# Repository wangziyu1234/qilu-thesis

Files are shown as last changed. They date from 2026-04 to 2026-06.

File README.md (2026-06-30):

# 智能仓储自主移动机器人结构设计与控制

> **齐鲁工业大学 · 机械工程学院 · 2026届本科毕业论文（设计）**
>
> 答辩人：王子煜 ｜ 指导教师：刘鹏博 ｜ 学号：202201230042

---

## 项目简介

针对中小型仓储场景中物料搬运自动化程度不足的问题，**从零设计了一款集成剪叉式举升功能的双轮差速驱动移动机器人**。项目覆盖了产品开发的完整技术链条——从需求分析、方案论证、机械结构设计、电气系统选型，到运动学建模、路径规划算法、PID控制仿真验证，最终形成一套可落地的工程方案。

**一句话概括**：让一台 200 kg 的小车，载着 50 kg 货物，在货架间自主导航、精准停靠、平稳升降。

---

## 项目结构

```
bylw/
├── fangzhen/matlab/          # MATLAB 仿真代码（7个脚本 + Simulink模型）
├── lunwen/QLULatex/          # LaTeX 论文源码（98页）
├── 答辩PPT/                   # 答辩演示文稿
├── sw/                        # SolidWorks 小车结构设计文件
├── image/                     # 项目图片资源
├── 翻译/                      # 英文文献翻译
├── 开题/                      # 开题报告
├── 中期检查/                   # 中期检查材料
├── 相关表格模板/               # 论文相关模板
├── 嘉立创单片机原理图/         # PCB 设计文件
├── gen_ppt_final.py           # PPT 自动生成脚本
├── cascaded_pid_agv.slx       # Simulink 双环PID模型
└── 答辩准备_原理与问答.md       # 答辩问答准备
```

---

## 系统架构

```
┌─────────────────────────────────────────────────────┐
│                   决策层（离线）                       │
│   Hybrid A* 全局路径规划 → 5种曲率 × 2方向 = 10基元    │
│   10m×8m 仓储地图 · 5个货架障碍物 · 路径 11.04 m       │
└──────────────────────────┬──────────────────────────┘
                           │ 参考路径
┌──────────────────────────▼──────────────────────────┐
│                   执行层（在线 · 5 ms 周期）            │
│   5路TCRT5000红外传感器 → 加权偏移 → PID纠偏            │
│   RMS 横向误差 1.5 cm · 最大误差 6.8 cm               │
└──────────────────────────┬──────────────────────────┘
                           │ ω_cmd
┌──────────────────────────▼──────────────────────────┐
│                   控制层（双环PID级联）                 │
│   外环·位姿环（PID） → 内环·轮速环（PI）                │
│   位姿环: Kp=3.0/Ki=0.2/Kd=0.4                       │
│   轮速环: Kp=17.0/Ki=103.0 · 抗积分饱和               │
└──────────────────────────┬──────────────────────────┘
                           │ PWM
┌──────────────────────────▼──────────────────────────┐
│                   驱动层（硬件）                       │
│   SMC80S 伺服电机(400W) × ZJPX115 行星减速器(40:1)     │
│   STM32F103C8T6 主控 · 编码器 10000脉冲/转             │
│   TCRT5000红外 ×5 · HC-SR04超声波 · 2500P/R编码器     │
└─────────────────────────────────────────────────────┘
```

---

## 核心指标一览

| 🏗️ 结构强度 | 🎯 控制精度 | 🗺️ 路径规划 |
|:---:|:---:|:---:|
| 臂杆应力 **5.56 MPa** | 定点误差 **2.2 cm** | 路径长度 **11.04 m** |
| 许用应力 156.7 MPa | 航向误差 **< 1°** | 搜索迭代 3134 次 |
| 安全裕度 **96.5%** | 线速度 RMSE **0.0086 m/s** | 满足运动学约束 |
| 屈曲安全系数 **10.1** | 循迹 RMS **1.5 cm** | 无需后处理平滑 |

---

## 快速开始

### 编译论文

```bash
cd lunwen/QLULatex/QLUThesisLatexTemplate-master/Thesis
xelatex main.tex && bibtex main && xelatex main.tex && xelatex main.tex
# 输出: main.pdf (98页)
```

### 运行仿真

```matlab
cd fangzhen/matlab
run_all          % 一键运行全部仿真
% 或单独运行：
traj_sim         % 四类典型轨迹仿真
hybrid_astar     % Hybrid A* 路径规划
tracking_pid     % 红外传感器PID循迹
pid_control      % 双环PID vs 单环PID对比
```

### 生成答辩PPT

```bash
python gen_ppt_final.py
# 输出: 答辩PPT/ppt.pptx（10页，含演讲稿备注）
```

---

## 论文结构

| 章节 | 内容 | 字数 | 占比 |
|---|---|:---:|:---:|
| 第1章 引言 | 研究背景、国内外现状、研究方法 | 2,979 | 11.1% |
| 第2章 总体设计 | 需求分析、6项方案对比选型 | 5,290 | 19.8% |
| 第3章 机械结构 | 剪叉机构设计、运动学、强度校核、FEA | 4,033 | 15.1% |
| 第4章 电气系统 | STM32主控、电机选型、传感器、电路设计 | 5,207 | 19.4% |
| 第5章 运动学与仿真 | 运动学建模、Hybrid A*、循迹PID | 4,475 | 16.7% |
| 第6章 运动控制 | 双环PID设计、4项仿真验证、双环vs单环对比 | 3,514 | 13.1% |
| 第7章 结论 | 工作总结、不足与改进、应用前景 | 1,281 | 4.8% |
| **正文合计** | | **26,779** | |
| 摘要 | 中英文摘要 | 756 | |
| 致谢+附录 | 致谢、附录程序说明 | 423 | |
| **全论文** | texcount 正文词数 | **28,137** | |
| 浮动体 | 图 + 表 | **61** | |

> 统计工具：`texcount -total -inc main.tex`，统计范围为正文段落文字（不含公式、图表标题、表格内容、参考文献）。

---

## 仿真结果

### 双环PID vs 单环PID（含负载扰动）

> 在电机动力学中加入正弦负载扰动 $d(t) = 1.5\sin(0.8t)$ N，模拟地面摩擦变化

| 场景 | 评价指标 | 双环PID | 单环PID | 提升倍数 |
|:---:|:---:|:---:|:---:|:---:|
| 阶跃响应 | 速度稳态误差 | 0.002 m/s | 0.093 m/s | **46×** |
| 定点镇定 | 位置误差 | 0.020 m | 0.072 m | **3.6×** |
| S形轨迹 | 线速度 RMSE | 0.007 m/s | 0.067 m/s | **9.6×** |
| 圆形跟踪 | 轨迹圆度 RMSE | 0.020 m | 0.061 m | **3×** |

**结论**：内环速度闭环在动态工况下优势显著，S形轨迹差距最大（9.6 倍），验证了级联控制的抗扰能力。

### 结构强度校核

| 部件 | 应力/指标 | 许用值 | 利用率 |
|:---:|:---:|:---:|:---:|
| 剪叉臂杆（压弯组合） | 5.56 MPa | 156.7 MPa | **3.5%** |
| 承载平台（von Mises） | 14.1 MPa | 156.7 MPa | **9.0%** |
| 铰接销轴（弯曲） | 8.7 MPa | 236.7 MPa | **3.7%** |
| 耳板（承压） | 6.8 MPa | 235 MPa | **2.9%** |
| 臂杆屈曲安全系数 | 10.1 | ≥ 3 | — |

> 所有部件应力利用率均在 10% 以内，结构安全裕度充足。FEA 数值解与理论手算偏差 < 1%，相互印证。

---

## 技术栈

| 领域 | 工具 | 用途 |
|---|---|---|
| 仿真计算 | MATLAB R2025a | 运动学建模、Hybrid A*、PID 控制、有限元分析 |
| 论文排版 | XeLaTeX (TeX Live 2026) | 中英文混排、公式、图表、参考文献 |
| 机械建模 | SolidWorks | 三维结构设计、装配体 |
| 嵌入式 | STM32CubeMX | 单片机外设配置、引脚分配 |
| 自动化 | Python + python-pptx | 答辩 PPT 自动生成 |
| 版本管理 | Git | 源码版本控制 |

---

## 开发日志

> 记录从开题到答辩的完整写作历程，共 **54 天**，**80+ 次提交**。

| 时间 | 里程碑 | 关键动作 |
|:---:|---|---|
| 4/15 | 🎬 项目启动 | 创建仓库，引入 QLUThesis LaTeX 模板，配置参考文献 |
| 4/18–4/29 | 📝 初稿框架 | 搭建论文结构，调整用语使其符合本科生论文水平，整理项目目录 |
| 5/09–5/16 | 📊 仿真推进 | 补充 MATLAB 仿真脚本（轨迹仿真、Hybrid A*、循迹PID），更新论文正文与图片 |
| 5/19 | 🔬 20号节点 | 完成阶段性版本，重构附录、重写摘要、优化代码注释与文件命名 |
| 5/26–5/28 | 📐 FEA 验证 | 补充有限元分析内容，统一 PID 参数与仿真图一致，修正销轴材料参数，全编译更新 |
| 5/30 | 📋 回应盲审 | 针对评阅专家意见补充减速器选型分析与实物测试计划 |
| 6/03–6/05 | 🎤 答辩准备 | 更新论文正文与仿真代码，完成答辩 PPT 最终版，整理工作区 |
| 6/06 | ✨ 排版冲刺 | 双环PID对比实验、全文公式补充、图表排版优化（[H]→[htbp]）、图文精简、README 重写 |
| 6/07 | ✅ 定稿提交 | 修正摘要与正文对应（直线跟踪→S形轨迹跟踪），补充完整答辩评语，最终编译 PDF（100页） |

```
4月 ████████░░░░░░░░░░░░░░░░░░░░░░  项目启动 + 初稿框架
5月 ░░░░░░░░████████████████████░░  仿真 + FEA + 盲审回复
6月 ░░░░░░░░░░░░░░░░░░░░░░░░██████  答辩准备 + 排版冲刺 + 定稿
```

---

## 参考资料

- 论文模板：[QLUThesisLatexTemplate](https://github.com/xlywy/QLUThesisLatexTemplate)（MIT License）

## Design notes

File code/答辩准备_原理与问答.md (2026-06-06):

# 论文答辩备考文档：智能仓储自主移动机器人结构设计与控制

---

> **使用说明**：本文档分为三大部分——核心原理解析（逐章讲解）、常见问答（42 题含标准答案）、考前自检清单。建议先通读原理部分建立知识框架，再用问答部分模拟答辩，最后用自检清单查漏补缺。

---

## 一、论文核心原理解析

---

### 第1章：引言与研究背景

---

### ### 0. 研究背景与文献综述要点

**市场数据（答辩时可用于说明研究意义）**：
- 2024 年我国网络零售额 15.5 万亿元，同比增长 7.2%，连续 12 年保持全球最大网络零售市场
- 中国 AGV 行业规模从 2019 年 48.27 亿元增至 2024 年 95.49 亿元
- AMR 市场 2023 年规模突破 60 亿元，年增长率超 30%

**国外研究现状要点**：
- 亚马逊 Kiva（2012 年收购）：以"货架到人"模式将拣选效率提高 2-3 倍，中央调度协调多机协同
- Fetch Robotics、Locus Robotics：利用激光雷达和 SLAM 实现自主定位，无需改造仓库地面
- Magazino TORU：从搬运货架到视觉抓取单品的技术跨越
- KUKA/ABB：机械臂与移动底盘结合的复合型移动操作机器人
- 算法方面：Hybrid A* 被广泛采纳，MAPF 为多机协同提供理论支撑，近年焦点转向深度强化学习（DQN、PPO）

**国内研究现状要点**：
- 京东物流：亚洲一号智能仓群，自主研发"地狼"AGV 和"天狼"穿梭系统
- 菜鸟网络：无锡、惠阳等地部署数百台 AGV 与 AMR，"小蛮驴"配送机器人
- 海康威视、旷视科技、快仓：形成成熟产品线，国产化产业链逐步成形
- 技术迭代：磁条/二维码 → 激光 SLAM → 视觉 SLAM

**路径规划算法研究现状**：
- 国外：DQN/DDQN 引入导航避撞学习、改进 A*+DWA 融合、自适应随机梯度下降线性回归
- 国内：MPC+PID 双闭环控制、改进哈里斯鹰优化算法、RRT*+DWA 融合、改进蚁群算法、动态优先级多 AGV 无冲突路径规划

---

### 第2章：总体方案设计

---

### ### 1. 差速驱动原理

**是什么？**

差速驱动（Differential Drive）是一种依靠左右两侧独立驱动的轮子，通过两轮速度差来实现转向的驱动方式。本设计中AGV采用两个独立驱动轮+四个随动万向轮的布局——两个驱动轮各自连接一台伺服电机，四个万向轮只起支撑作用不参与驱动。

**为什么选差速而不是单轮/全向驱动？**

| 对比维度 | 差速驱动 | 单轮驱动+舵机转向 | 麦克纳姆轮（全向） |
|---|---|---|---|
| 机械复杂度 | 低（无转向机构） | 中（需要舵机） | 高（轮毂结构复杂） |
| 控制难度 | 低（只控两轮转速） | 中（需协调驱动+转向） | 高（四轮独立速度分解） |
| 承载能力 | 强（标准橡胶轮） | 中 | 弱（辊子易磨损） |
| 定位精度 | 中（依赖编码器） | 高 | 中 |
| 成本 | 低（2电机） | 中（电机+舵机） | 高（4个特种轮） |
| 地面适应性 | 好 | 好 | 差（对平整度要求高） |
| 效率 | 一般（转向有滑移） | 较高 | 高（可平移） |

**为什么差速是最优选？** 仓储AGV的核心需求是：承载重物（50kg）、在平整的仓库地面上可靠运行、成本可控。差速驱动虽然无法像麦克纳姆轮那样横向平移，但在标准货架通道中（通常宽1.2m以上），差速AGV完全可以通过原地转向完成所有需要的位姿调整。而全向轮在重载下辊子磨损严重、寿命有限，对于仓储场景反而"过度设计"了。

**物理机制——如何通过轮速差实现转向？**

想象你在推一辆超市购物车：如果你左手用力推、右手不动，车就会向右转。差速驱动是同样的道理：

- **左轮快、右轮慢** → 机器人向右转（逆时针方向）
- **右轮快、左轮慢** → 机器人向左转（顺时针方向）
- **两轮等速** → 直线前进或后退
- **左轮正转、右轮反转（等速）** → 原地旋转（零转弯半径）

严谨来说，设轮距为 $L = 0.52$ m（两驱动轮中心距离），轮半径 $r = 0.09$ m，左轮线速度为 $v_L$，右轮线速度为 $v_R$，则：

- 机器人中心线速度：$v = \frac{v_L + v_R}{2}$
- 机器人角速度：$\omega = \frac{v_R - v_L}{L}$

转弯半径：$R = \frac{v}{\omega} = \frac{L}{2} \cdot \frac{v_L + v_R}{v_R - v_L}$

当 $v_L = -v_R$ 时，$R = 0$，即原地旋转——这是差速驱动独有的优势，舵机转向的汽车永远做不到。

**设计要点**：
1. 轮距 $L$ 是核心参数，$L$ 越大角速度响应越灵敏（同样的轮速差产生更大的转弯效果），但占用空间也越大
2. 两个驱动轮直径必须一致，否则直线时也会有偏航
3. 万向轮要放在驱动轮轴线后方（"前驱后从"布局），保证直行稳定性

---

### ### 2. 剪叉式升降机构

**是什么？**

剪叉式升降机构（Scissor Lift Mechanism）由多组交叉的臂杆组成，通过改变臂杆之间的夹角来实现平台的垂直升降。像一个可以展开和折叠的"X"形支架——多个X串联起来，就能在很小的初始高度下获得很大的升降行程。

**为什么选剪叉式？**

| 方案 | 优点 | 缺点 |
|---|-----|---|
| 剪叉式 | 结构简单、承载力大、收缩高度低、行程大 | 速度不快、高位稳定性下降 |
| 液压直推式 | 推力极大、速度可控 | 需要液压泵站、有泄漏风险、不适合小型AGV |
| 丝杆升降式 | 精度高、自锁性好 | 行程受丝杆长度限制、速度慢 |
| 链条提升式 | 行程长 | 晃动大、精度低 |
| 气动式 | 速度快 | 位置难以精确定位、承载力有限 |

对于仓储AGV而言，需要在有限的车体高度内把货物举升到1m左右的高度，剪叉式是唯一能同时满足"低收缩高度+大行程+结构简单+成本低"的方案。

**升降高度与臂杆角度的数学关系**

设单根臂杆长度为 $L$（销孔中心距），两臂间夹角为 $\alpha$，臂杆与水平面的夹角（水平半角）为 $\beta = \alpha/2$，台面高度 $H$ 与 $\beta$ 的关系为：

$$H = L \cdot \sin\beta + h_0$$

其中 $h_0 \approx 49$ mm 为臂杆两端配件（铰座、滚轮及连接件）对台面高度的固定贡献值。

底部滑动端的水平位移 $x_s = L \cdot \cos\beta$，消去 $\beta$ 可得 $H = \sqrt{L^2 - x_s^2} + h_0$。

本设计采用单层剪叉（两根等长臂杆在中点交叉铰接），臂杆长度 $L = 600$ mm（销孔中心距），截面为 36 mm × 4.8 mm 的 Q235 实心扁钢，宽面竖直布置。$\alpha$ 范围 $19.10° \sim 133.49°$，对应 $\beta = \alpha/2$ 范围 $9.55° \sim 66.75°$：

- 最低位 $\beta_{\min} = 9.55°$ → $H_{\min} = 600 \times \sin(9.55°) + 49 \approx 149$ mm
- 最高位 $\beta_{\max} = 66.75°$ → $H_{\max} = 600 \times \sin(66.75°) + 49 \approx 600$ mm

升降总行程约 $452$ mm，满足 0.45 m 设计指标。

**有限元数值验证**：论文采用 MATLAB 编写有限元分析程序进行数值验证。臂杆采用 30 个平面梁单元离散，台面板采用 Navier 级数解取前 21×21 项计算。

> **口语版**：有限元就是把一根完整的杆"切成"30 小段，每小段单独算受力，再拼回来看整体效果。Navier 级数解是算薄板变形的经典数学方法——把板的弯曲"拆成"很多正弦波叠加，取的项越多越精确，就像用越来越多的乐高积木拼出一个曲面。

结果：臂杆组合应力有限元解约 5.60 MPa，与理论手算值 5.56 MPa 偏差 <1%；台面板中心挠度约 0.47 mm、**von Mises 等效应力**约 14.1 MPa，与解析解一致。

> **von Mises 应力是什么？** 简单说，材料内部的受力方向很复杂（有压、有拉、有剪切），von Mises 把这些"五花八门的力"换算成一个等效的单一数字，拿来跟材料的屈服强度比较。就像考试把语文数学英语折算成一个总分，总分超了就"挂科"（屈服）。

**设计要点**：
1. 角度不宜太小（太低时需要的推力急剧增大，最低位为最危险工况）
2. 角度不宜太大（接近 180° 时稳定性急剧下降）
3. 臂杆材料选 Q235 钢（屈服强度 235 MPa），保证强度同时成本可控
4. 驱动方式：电动推杆推动底部滑动端，力通过剪叉传递

---

### ### 3. 控制方案选型逻辑

**为什么用单片机（STM32）而不是PLC/DSP/工控机？**

| 方案 | 典型应用 | 优点 | 为什么不用 |
|---|---|---|---|
| **STM32单片机** ✅ | 嵌入式实时控制 | 成本低（约30元）、体积小、实时性好、功耗低 | — |
| PLC | 工业产线控制 | 可靠性极高、编程方便（梯形图） | 体积大、成本高（数千元）、不适合移动平台 |
| DSP | 复杂信号处理 | 浮点运算极快 | 过强（本设计不需要FFT/滤波等复杂运算）、成本高 |
| 工控机 | 上位机/视觉 | 算力强、可跑Linux | 功耗大、体积大、实时性不如裸机单片机 |

选型逻辑：AGV小车空间紧凑、电池供电、需要实时响应编码器脉冲和传感器信号，STM32F103的72MHz主频和丰富定时器外设完全胜任，且成本仅为PLC的几十分之一。

**为什么用PID而不是模糊控制/MPC？**

| 方案 | 优点 | 为什么不用 |
|---|---|---|
| **PID** ✅ | 简单可靠、调参直观、无需模型、90%工业控制场景在用 | — |
| 模糊控制 | 不依赖精确模型、非线性系统适用 | 规则库设计依赖经验、调试困难、难以证明稳定性 |
| MPC（模型预测控制） | 可处理约束、预测未来轨迹 | 计算量大（需要在线求解优化问题）、STM32难以实时运行 |
| LQR | 最优控制、数学优雅 | 需要精确数学模型、对参数敏感 |

**选PID的根本原因——够用原则**：差速AGV是一个线性度较好的系统（速度与PWM占空比近线性），PID完全能控制好。只有在非线性强、模型复杂（如倒立摆、四旋翼）的场景，才值得引入更复杂的控制方法。

**为什么用Hybrid A\*而不是Dijkstra/标准A\*？**

| 算法 | 搜索空间 | 路径特点 | 为什么不够好 |
|---|---|---|---|
| Dijkstra | 栅格(x,y) | 最短路径，无启发式 | 搜索太慢（盲目搜索），路径"贴墙走"不安全 |
| A\* | 栅格(x,y) | 最短路径，有启发式 | 路径是栅格折线，不满足车辆转弯半径约束 |
| **Hybrid A\*** ✅ | 连续(x,y,θ) | 平滑、满足运动学约束 | — |

标准A\*在栅格地图上搜索，只能走"上下左右+对角"八方向，生成的路径是锯齿折线。差速AGV虽然能原地旋转，但更希望得到平滑连续的路径来减少运动中的停顿和磨损。Hybrid A\*将状态空间从$(x, y)$扩展到$(x, y, \theta)$，用运动基元（圆弧、直线）作为搜索步长，规划出的路径天然满足差速运动学约束。

---

### ### 4. 交流伺服电机 vs 步进电机/直流有刷电机

| 类型 | 控制方式 | 优点 | 缺点 |
|---|---|---|---|
| **交流伺服电机** ✅ | 闭环（编码器反馈） | 精度高、响应快、过载能力强、效率高 | 成本较高、需要专用驱动器 |
| 步进电机 | 开环（脉冲+方向） | 成本低、控制简单 | 易丢步（高速/重载时）、效率低、发热大 |
| 直流有刷电机 | 电压调速 | 成本最低、控制极简 | 电刷磨损（寿命短）、电磁干扰大、效率低 |
| 无刷直流电机 | 闭环 | 效率高、寿命长 | 需要电子换向、控制较复杂 |

**选型依据**：
1. **精度**：AGV需要精确控制轮速来实现航位推算和轨迹跟踪，伺服电机配2500P/R编码器可实现0.036°的角度分辨率，步进电机开环控制无法保证
2. **过载能力**：伺服电机通常可承受3倍额定转矩的短时过载（加速/爬坡时用到），步进电机一过载就丢步
3. **效率**：电池供电的AGV对功耗敏感，伺服电机效率通常在85%以上，步进电机可能低至50-60%
4. **寿命**：仓储AGV需要7×24小时运行，直流有刷电机的电刷是消耗件，维护成本高

**减速器选型推导**：理论减速比 56.55，实际选用 ZJPX115 型二级行星减速器（减速比 40，效率 93%，寿命 20000 h）。差异通过伺服驱动器限速补偿（限速至 2122 r/min）。ZJPX115 额定输出扭矩 90 N·m，电机 1.27 N·m × 40 × 0.93 ≈ 47.2 N·m，满足 22.5 N·m 需求。

---

### 第3章：机械结构设计

---

### ### 5. 剪叉机构运动学

**三个关键角度的关系**

在剪叉机构中，存在两个容易混淆的角度：

- **臂杆夹角** $\alpha$：同侧上下两根臂杆之间的夹角（决定了剪叉的"张开程度"）
- **水平半角** $\beta$：单根臂杆与水平面之间的夹角（决定了当前高度）

它们的几何关系是：$\beta = \alpha / 2$

为什么？因为剪叉机构是对称的——当上臂杆和下臂杆与水平面的夹角相等时，它们之间的夹角自然就是两倍：$\alpha = 2\beta$。

**台面高度 $H$ 的推导**

对于单层剪叉（两根等长臂杆在中点交叉铰接），高度为：

$$H = L \cdot \sin\beta + h_0 = L \cdot \sin(\alpha/2) + h_0$$

其中 $h_0 \approx 49$ mm 为臂杆两端配件对高度的固定贡献。两臂夹角 $\alpha$ 与水平半角 $\beta$ 满足 $\beta = \alpha/2$。

代入具体数值，$L = 600$ mm：

- $\alpha = 19.10°$，$\beta = 9.55°$（最低位）：$H = 600 \times \sin(9.55°) + 49 \approx 149$ mm
- $\alpha = 133.49°$，$\beta = 66.75°$（最高位）：$H = 600 \times \sin(66.75°) + 49 \approx 600$ mm

理论升程约 451 mm。

**为什么最低位是最危险工况？**

这是很多人容易想反的问题。直观上可能觉得升到最高位时最危险（"高处容易倒"），但实际上**最低位才是受力最恶劣的工况**。

原因在于力的分解：额定载荷下臂杆轴向力 $F_{\text{arm}} = F/(4\sin\beta)$（$F=490.5$ N 为额定载荷力）。

- $\beta = 9.55°$ 时，$\sin\beta \approx 0.166$ → $F_{\text{arm}} \approx 739$ N
- $\beta = 66.75°$ 时，$\sin\beta \approx 0.919$ → $F_{\text{arm}} \approx 134$ N

最低位臂杆轴向力约为最高位的 **5.5 倍**，因此最低位是最危险工况。

当 $\beta$ 很小时，$\sin\beta$ 很小，臂杆内产生的轴向压力非常大——就像试图用一根近乎水平的棍子去撬东西，需要极大的力才能产生一点点竖直运动。

**工作角度范围的意义**：
- 下限 $\alpha = 19.10°$（$\beta = 9.55°$）：由电动推杆的最大推力决定
- 上限 $\alpha = 133.49°$（$\beta = 66.75°$）：由机构几何约束决定
- 这个范围对应了约 451 mm 的有效升降行程，满足 0.45 m 的设计指标

---

### ### 6. 强度校核方法

**臂杆的压弯组合应力**

臂杆在工作时承受两种应力：

1. **轴向压应力** $\sigma_{axial}$：来自负载和自重在臂杆方向的分力
   $$\sigma_{axial} = \frac{F_N}{A}$$
   其中 $F_N$ 为轴向压力，$A$ 为臂杆截面积

2. **弯曲应力** $\sigma_{bending}$：来自负载偏心、自重弯矩
   $$\sigma_{bending} = \frac{M \cdot y_{max}}{I}$$
   其中 $M$ 为弯矩，$y_{max}$ 为截面最远点到中性轴的距离，$I$ 为截面惯性矩

组合应力（叠加原理）：
$$\sigma_{max} = \sigma_{axial} + \sigma_{bending} = \frac{F_N}{A} + \frac{M \cdot y_{max}}{I}$$

**Q235 钢材料参数**：

| 参数 | 数值 |
|---|---|
| 屈服强度 $\sigma_s$ | ≥235 MPa |
| 抗拉强度 $\sigma_b$ | 375–500 MPa |
| 延伸率 $\delta$ | ≥26% |
| 弹性模量 $E$ | ≈2.06×10⁵ MPa |
| 密度 $\rho$ | 7.85 g/cm³ |
| 泊松比 $\nu$ | 0.3 |

**许用应力与安全系数**

许用应力 $[\sigma]$ 是材料"被允许承受的最大应力"，等于材料屈服强度除以安全系数：

$$[\sigma] = \frac{\sigma_s}{n}$$

- 材料为 Q235 钢，屈服强度 $\sigma_s = 235$ MPa
- 安全系数 $n = 1.5$（考虑冲击载荷、制造误差等因素）
- 许用应力：$[\sigma] = 235 / 1.5 \approx 156.7$ MPa

**为什么实际应力远小于许用应力？**

计算得实际最大应力约 $5.56$ MPa（轴向 4.28 MPa + 弯曲 1.28 MPa），仅为许用应力 $156.7$ MPa 的 $3.5\%$。

这**不是浪费材料**，而是因为：
1. 截面尺寸主要由**屈曲稳定性**决定（见下一节），而非强度
2. 剪叉机构的臂杆是细长杆，在应力还远未达到材料屈服极限之前，就可能发生失稳
3. 扁钢的标准截面规格有限（36×4.8 mm），选用了市场上可买到的规格，自然有富余

**通俗版理解**：就像一根 2 米长的细竹竿，你竖着压它，在它还远远没有"被压断"之前就弯了（失稳）。所以设计细长杆时，往往不是强度不够，而是稳定性不够。

---

### ### 7. 屈曲稳定性概念

**什么是压杆失稳？**

取一把塑料尺，竖着放在桌上，用手掌从上往下压——当压力达到某个临界值时，尺子会突然向一侧弯曲，这就是失稳（Buckling）。

失稳的核心特征是：**不是材料被压坏了（应力没超极限），而是结构形态发生了突变**。这就像一根头发丝，你顺着轴向压它很难压断，但它一碰就弯——不是因为头发不结实，而是因为太细长。

**长细比 $\lambda$ 的意义**

长细比是衡量一根杆"容不容易失稳"的指标：

$$\lambda = \frac{\mu \cdot l}{i}$$

其中：
- $\mu$：长度系数（两端铰支 $\mu = 1$，两端固定 $\mu = 0.5$，一端固定一端自由 $\mu = 2$）
- $l$：臂杆实际长度
- $i = \sqrt{I/A}$：截面惯性半径（只与截面形状有关）

本设计 $\lambda = 431.7$，而材料弹性极限对应的临界长细比 $\lambda_p = 104$。

$\lambda \gg \lambda_p$ 的含义是：**杆件非常细长，在应力还远未达到材料屈服强度之前就会发生弹性失稳**——属于"大柔度杆"，必须用欧拉公式计算临界载荷。

**欧拉公式**（适用于 $\lambda > \lambda_p$ 的大柔度杆）：

$$F_{cr} = \frac{\pi^2 \cdot E \cdot I}{(\mu \cdot l)^2}$$

其中 $E$ 为材料的弹性模量（Q235 钢约 $2.06 \times 10^{5}$ MPa），$I$ 为截面惯性矩（弱轴方向 $I_{\text{弱}} = 332$ mm⁴）。

关键结论：**临界载荷与长度平方成反比**——杆长加倍，临界载荷降为原来的四分之一。这也是为什么细长杆设计需要特别谨慎。

**为什么加侧向支撑后安全系数从2.54升到10.1？**

侧向支撑的本质是**减小有效长度** $l$。本设计在两侧臂杆之间增设侧向支撑隔套：

- 原有效长度：$l = 600$ mm
- 加支撑后有效长度：$l/2 = 300$ mm（支撑点将一根长杆分成两段短杆）
- 临界载荷增加：$F_{cr}' / F_{cr} = (600/300)^2 = 4$ 倍
- 原安全系数 2.54 → 加支撑后 10.14

这就是平方关系的威力。

> **口语版**：为什么加一个小隔套效果这么大？因为临界载荷跟长度的平方成反比——长度砍一半，承载能力翻四倍。就像你拿一根长竹竿，中间绑一根绳子把它跟旁边的杆子拴在一起，竹竿就不容易弯了。加支撑比换粗竹竿省力得多。

实际结构设计中，往往不是"加粗杆件"而是"加支撑"——效果更显著且不增加重量。

---

### ### 8. 销轴剪切校核

**双面剪切的概念**

剪叉机构的臂杆连接处使用销轴（销钉）。当剪叉受力时，销轴承受的是剪切力——上下两块板试图沿相反方向错动，像剪刀剪纸一样"剪"销轴。

双面剪切是指：销轴在**两个截面**上同时承受剪切力。因为臂杆连接处通常是一个"叉耳"结构——一个U形叉夹住一根杆，销轴穿过两侧叉耳和中间的杆——力在叉耳的两侧分别传递，所以销轴有两个剪切面。

每个剪切面承受的力只有总力的一半：

$$\tau = \frac{F}{2 \cdot A_{pin}}$$

其中 $A_{pin} = \pi d^2 / 4$ 为销轴截面积。

**承载力计算**：

销轴材料（45 钢调质）的剪切屈服强度 $\tau_s \approx 0.6 \times \sigma_s = 0.6 \times 355 = 213$ MPa

销轴直径 $d = 18$ mm，截面积 $A = \pi \times 9^2 = 254.5$ mm²

双面剪切承载力：$F_{max} = 2 \times A \times [\tau] = 2 \times 254.5 \times 142 \approx 72.3$ kN（取安全系数 1.5，$[\tau] = 213/1.5 = 142$ MPa）

安全系数 $n = 72.3 \times 10^3 / 739.1 \approx 97.8$，等效承载能力约 4890 kg，远超 50 kg 额定载重。

**销轴弯曲校核**：

耳板内间距实测 $L_s = 27$ mm，销轴跨中弯矩：

$$M_{pin} = \frac{F_{arm} \cdot L_s}{4} \approx \frac{739.1 \times 27}{4} \approx 4.99 \times 10^3 \text{ N·mm}$$

$$W_{pin} = \frac{\pi d^3}{32} = \frac{\pi \times 18^3}{32} \approx 572.6 \text{ mm}^3$$

$$\sigma_{pin} = \frac{M_{pin}}{W_{pin}} \approx 8.7 \text{ MPa} \ll [\sigma] = 236.7 \text{ MPa}$$

弯曲应力远小于 45 钢许用应力，安全。

**耳板孔壁承压应力校核**（耳板厚度 $t = 6$ mm）：

$$\sigma_{brg} = \frac{F_{arm}}{D \cdot t} = \frac{739.1}{18 \times 6} \approx 6.8 \text{ MPa}$$

远低于 Q235 钢的许用承压应力（约 235 MPa），耳板连接强度满足要求。

**承载平台强度校核**（Navier 级数解）：

平台为 660 mm × 312 mm × 3 mm 的 Q235 矩形薄板，四边简支，50 kg 均布载荷。

> **口语版**：承载平台就是一块 3 mm 厚的钢板，货物放在上面。我们要算它会不会被压弯变形太大。用 Navier 级数解是因为"四边被托住的薄板"有现成的数学公式——把板的弯曲形状拆成很多正弦波叠加，取的项越多越精确。

采用 Navier 级数解取前 51×51 项求和：
- 均布载荷 $q = F/(a \cdot b) = 490.5/(660 \times 312) \approx 2.38 \times 10^{-3}$ MPa
- 板弯曲刚度 $D_{plate} = Et^3/[12(1-\nu^2)] \approx 5.09 \times 10^5$ N·mm
- 最大挠度 $w_{max} \approx 0.47$ mm（挠跨比约 $b/669$）
- $\sigma_{x,max} \approx 7.0$ MPa，$\sigma_{y,max} \approx 16.2$ MPa
- von Mises 等效应力 $\sigma_{vm} \approx 14.1$ MPa < $[\sigma] = 156.7$ MPa，利用率 9.0%

> **0.47 mm 挠度是什么概念？** 大约是 5 张 A4 纸的厚度。放在 660 mm 长的钢板上，肉眼几乎看不出来，完全不影响使用。

**为什么实际载荷远小于承载力？**

满载 50 kg 的 AGV，单根臂杆传递的轴向力仅为 739 N（约 0.074 吨力），远小于销轴的 72.3 kN 承载力。

这同样是"非强度主导"的设计——销轴直径不是由剪切强度决定的，而是由结构尺寸（臂杆截面宽度、装配方便性）和标准件规格决定的。选 M18 的销轴不是因为需要这么粗，而是因为这是标准规格中刚好与臂杆截面匹配的尺寸。

---

### 第4章：电气系统设计

---

### ### 9. STM32F103C8T6 核心芯片

**ARM Cortex-M3 架构特点**

STM32F103C8T6 基于 ARM Cortex-M3 内核，这是一款为嵌入式实时控制设计的32位处理器架构：

- **哈佛结构**：指令总线和数据总线分开，可以同时取指令和读数据
- **三级流水线**：取指→译码→执行，每个时钟周期可以完成一条指令
- **嵌套向量中断控制器（NVIC）**：支持中断嵌套，高优先级中断可以打断低优先级
- **位带操作**：可以像操作普通变量一样操作单个IO口的某一位，无需读-修改-写

**72MHz、64KB Flash、20KB RAM 够用吗？**

非常够用。让我们算一笔账：

- 差速AGV的控制循环频率通常在100-200Hz（即每5-10ms一个周期）
- 72MHz = 7200万条指令/秒，一个控制周期（5ms）可以执行约36万条指令
- PID计算只需要几十条指令，Hybrid A\*路径规划是离线完成的（在PC上运行，不是STM32上）
- 20KB RAM 对于存储传感器读数、编码器计数、PID状态变量来说十分充裕
- 64KB Flash 可以容纳几万行C代码，控制程序通常只有几千行

**STM32 最小系统电路**：
- **电源**：ME6211C33 LDO 芯片（SOT-23-5 封装，输入 2-6V，输出 3.3V/500mA，待机电流 0.1μA）
- **滤波**：104 去耦电容（100 nF）滤除电源高频噪声
- **时钟**：外部 8 MHz 晶振 + 两个 12 pF 负载电容
- **调试**：SWD 两线接口（SWDIO + SWCLK），配合 ST-Link 烧录调试
- **复位**：NRST 引脚内部上拉，按键拉低触发复位，电容滤除抖动

**定时器编码器接口如何实现四倍频测速？**

STM32的通用定时器集成了**编码器模式（Encoder Mode）**。编码器的A、B两相输出是两路相位差90°的方波：

- A相超前B相90° → 正转
- B相超前A相90° → 反转

定时器硬件会自动检测A、B两相的每一个边沿（上升沿+下降沿），每相两个边沿，两相共四个边沿，所以编码器每转一圈会产生 $2500 \times 4 = 10000$ 个计数脉冲——这就是**四倍频**。

关键是：这一切是**硬件自动完成**的（定时器的编码器模式），不需要软件中断处理每个脉冲，不消耗CPU时间。CPU只需在控制周期到来时读取定时器的计数值即可。

**通俗版理解**：编码器就像自行车的码表，每转一圈发送2500个"嘀"声。但STM32不仅能听到"嘀"，还能听出每个"嘀"的上升和下降（就像能听出一个音符的开始和结束），所以一圈能数出10000个信号，精度提升了4倍。

---

### ### 10. 电机选型计算

**从车速到电机转速的完整链条**

需求：最高车速 $30\text{ m/min} = 0.5\text{ m/s}$

驱动轮直径 $D = 180$ mm，则：

$$\text{轮周长} = \pi \times D = \pi \times 0.18 \approx 0.565\text{ m}$$

$$\text{最高车速时的轮转速} = \frac{0.5\text{ m/s}}{0.565\text{ m}} \times 60 \approx 53.1\text{ r/min}$$

电机额定转速约 $3000\text{ r/min}$，则需要的减速比：

$$i = \frac{3000}{53.1} \approx 56.5$$

理论减速比 $i = 3000/53.05 \approx 56.55$。实际选用减速比 $i = 40$（ZJPX115 型二级精密行星减速器，满载效率 93%，平均寿命 20000 h，最大径向力 4330 N）。理论值与实际值的差异通过伺服驱动器限速补偿：当电机最高转速限制在约 $2122\text{ r/min}$ 时，减速后轮速约 $53.05\text{ r/min}$，对应线速度约 $30\text{ m/min}$。电机在 $3000\text{ r/min}$ 全速时实际最高车速约 $42.4\text{ m/min}$——这提供了**速度裕量**。所选电机型号为 SMC80S-0040-30AoK-3DKH，额定转矩 1.27 N·m，经 40 倍减速后连续输出扭矩约 $1.27 \times 40 \times 0.93 \approx 47.2$ N·m，满足驱动轮 22.5 N·m 的需求且留有充足余量。

**动态载荷分析**（论文中的详细估算）：
- 起步/制动惯性力：取加速度 0.3 m/s²，$F_a = 250 \times 0.3 = 75$ N，附加转矩 $M_a = 75 \times 0.09 / 2 \approx 3.38$ N·m
- 差速转弯偏载：外侧轮承载增大 10%–15%
- 峰值转矩需求：约稳态值的 1.3–1.5 倍，即约 29–34 N·m
- 电机峰值输出：$1.27 \times 3 \times 40 = 152.4$ N·m（3 倍过载系数），远高于需求

**传感器接口电路**：
- **红外传感器**：TCRT5000 输出数字量，信号线加 10 kΩ 上拉电阻拉高到 3.3V，加 100 nF 去耦电容滤除高频噪声
- **超声波传感器**：HC-SR04 的 Trig 接 PA1（输出），Echo 接 PA2（输入），5V 供电。Echo 为 5V 电平，需确认引脚 5V 容限条件，必要时加分压电路

**阻力系数 $\mu = 0.2$ 的取值依据**

阻力系数 $\mu = 0.2$ 综合了以下因素：
- 滚动摩擦系数（聚氨酯轮在环氧地坪上）：约 0.015–0.03
- 轴承摩擦（折算）：约 0.01–0.02
- 地面微小不平度造成的附加阻力：约 0.05–0.10
- 加速阻力（惯性力折算）：约 0.05–0.08

取 0.2 是一个**保守估计**（工程中常用的做法——往"更困难"的方向估计），实际值可能在 0.1–0.15 之间。

**为什么选 400W 而计算只需 132W？**

满载总质量 $m = 250$ kg（自重约 200 kg + 载重 50 kg），综合阻力 $f = \mu \cdot m \cdot g = 0.2 \times 250 \times 10 = 500$ N。单轮牵引力 $F = f/2 = 250$ N，驱动轮半径 $R = 0.09$ m：

输出转矩：$M = F \times R = 250 \times 0.09 = 22.5\text{ N·m}$

理论机械功率：$P_w = M \cdot n / 9550 = 22.5 \times 53.05 / 9550 \approx 0.125\text{ kW}$

计入减速箱效率 $\eta = 0.95$：$P_m = 0.125 / 0.95 \approx 0.132\text{ kW}$

实际选用 2 台 400W 伺服电机（各驱动一侧轮子），总功率 800W。与计算值 132W 相比看似浪费，但：
- 加速和制动时的峰值功率远超匀速功率（惯性力约 75 N，附加转矩约 3.38 N·m）
- 差速转弯时外侧轮承载增大 10%–15%
- 峰值转矩需求约为稳态值的 1.3–1.5 倍（约 29–34 N·m）
- 所选电机经 40 倍减速后峰值输出 $1.27 \times 3 \times 40 = 152.4\text{ N·m}$，远高于需求
- 功率裕量意味着更高的可靠性和更长的使用寿命

**通俗比喻**：就像买车，你平时只需要开到 120 km/h，但不会买一台刚好能跑 120 km/h 的发动机——你需要加速、超车、爬坡的裕量。选 400W 而不是 50W，就是在给 AGV 留"加速超车"的空间。

**动态载荷补充**：起步/制动时附加惯性力约 75 N（加速度 0.3 m/s²），附加转矩约 3.38 N·m；差速转弯外侧轮偏载 10%–15%；峰值转矩需求约稳态值的 1.3–1.5 倍（29–34 N·m）。电机峰值输出 152.4 N·m 远高于此。

---

### ### 11. 传感器协同策略

**TCRT5000（红外反射式）做循迹**

TCRT5000是一种红外反射式光电传感器，集成了红外发射管和接收管。工作原理：
- 红外发射管发出红外光（波长950nm，不可见）
- 照射到地面后被反射
- 红外接收管（光敏三极管）接收反射光
- **深色表面**（如黑色循迹线）：吸收红外光，反射弱 → 接收管电流小
- **浅色表面**（如白色地面）：反射红外光强 → 接收管电流大

有效检测距离：1-25mm（需要贴近地面安装）。模块板载 LM393 比较器，输出数字量（0/1），直接接 STM32 的 GPIO。

**两层导航架构说明**：本文采用"Hybrid A* 全局规划 + 红外循迹局部跟踪"的两层架构。Hybrid A* 解决"走哪条路"的问题（决策层），红外循迹解决"如何沿路走"的问题（执行层）。当仓储货架布局变化时，Hybrid A* 可基于更新后的地图重新规划路径，无需人工重新铺设引导标识。

**HC-SR04（超声波）做避障**

HC-SR04超声波测距模块：
- 发射40kHz的超声波脉冲
- 超声波遇到障碍物后反射回来
- 测量从发射到接收的时间差 $\Delta t$
- 距离 $d = \frac{v_{sound} \times \Delta t}{2}$（除以2是因为来回）
- 声速 $v_{sound} \approx 340\text{m/s}$（室温）
- 检测范围：2cm-400cm

**为什么这样分工？**

| 传感器 | 检测距离 | 检测目标 | 用途 |
|---|---|---|---|
| TCRT5000 | 1-25mm（近） | 地面颜色差异 | 循迹导航 |
| HC-SR04 | 2cm-4m（中远） | 障碍物 | 安全避障 |

分工逻辑：
- **红外循迹**解决"我在哪、我去哪"的问题（沿预定路线走）
- **超声波避障**解决"前面有没有障碍"的问题（不撞到东西）
- 两者互补，红外"近视"看地面，超声波"远视"看前方
- 这种协同策略成本极低（两个TCRT5000不到5元，一个HC-SR04不到10元），但功能完备

---

### ### 12. 编码器航位推算

**四倍频后10000脉冲/转**

2500P/R（Pulses per Revolution）编码器，经STM32定时器编码器模式四倍频后：
$$\text{脉冲/转} = 2500 \times 4 = 10000\text{脉冲/转}$$

每个脉冲对应的车轮转动角度：
$$\Delta\theta_{pulse} = \frac{360°}{10000} = 0.036°$$

每个脉冲对应的移动距离：
$$\Delta d_{pulse} = \frac{\pi \times D}{10000} = \frac{\pi \times 180\text{ mm}}{10000} \approx 0.057\text{ mm}$$

这意味着理论上的位移分辨率达到了**约 0.06 mm（6 丝）**级别。

**M法测速**

M法（测频法）的原理：在一个固定的采样周期 $T$ 内，统计编码器脉冲数 $M$，则：

$$n = \frac{M}{10000 \times T} \times 60 \quad \text{(r/min)}$$

或线速度：

$$v = \frac{M \times \pi D}{10000 \times T}$$

**M法的低速误差问题**：当车速很慢时，一个采样周期内可能只收到几个脉冲甚至0个脉冲，测速结果会出现严重的量化误差。比如 $T=10\text{ms}$，车速0.01m/s时每周期只有约2个脉冲——速度测量很不平滑。

> **口语版**：M 法就像用秒表数你一分钟心跳了多少下来推算心率。如果你心跳很快（60 次/分），数错了 1 次误差很小；但如果你心跳很慢（6 次/分），数错了 1 次误差就是 17%——根本测不准。低速时编码器脉冲就像"慢心跳"，数太少所以误差大。

解决方案：
- 在低速时切换到**T法（测周法）**：测量相邻两个脉冲之间的时间间隔
- 或在中速时使用**M/T法**（同时测脉冲数和时间）：精度最高，本设计采用此方法

**从左右轮编码器推算机器人位姿**

设采样周期 $\Delta t$ 内，左轮编码器计数 $N_L$，右轮编码器计数 $N_R$。本设计中轮距 $L = 0.52$ m，轮半径 $r = 0.09$ m（直径 180 mm）。

左轮位移：$\Delta s_L = N_L \times \frac{\pi D}{10000}$
右轮位移：$\Delta s_R = N_R \times \frac{\pi D}{10000}$

机器人中心位移：$\Delta s = \frac{\Delta s_L + \Delta s_R}{2}$
机器人转角变化：$\Delta \theta = \frac{\Delta s_R - \Delta s_L}{L}$（$L = 0.52$ m 为轮距）

位姿更新（航位推算 Dead Reckoning）：

$$\begin{cases}
x_{k+1} = x_k + \Delta s \cdot \cos(\theta_k + \Delta\theta / 2) \\
y_{k+1} = y_k + \Delta s \cdot \sin(\theta_k + \Delta\theta / 2) \\
\theta_{k+1} = \theta_k + \Delta\theta
\end{cases}$$

注意：$\cos$ 和 $\sin$ 中用的是 $\theta_k + \Delta\theta/2$（即转角变化量的一半），这是离散化时的一种近似——用运动区间中点处的航向角，比直接用 $\theta_k$ 更准确。

**航位推算的固有缺陷**：误差会累积。编码器只能测轮子转动，但测不出车轮打滑——如果轮子空转，编码器会误以为AGV在移动。

> **口语版**：航位推算就像你闭着眼睛走路——靠数步数来猜自己到了哪里。走直线还行，但如果脚底打了个滑（步数多算了），你就不知道自己偏到哪去了。而且越走越偏，因为每一步的误差会叠加上去。所以实际中需要时不时"睁眼看一下"（扫二维码或用激光定位）来纠正。

实际应用中通常需要配合其他绝对定位手段（如地面二维码、激光SLAM）定期校准。

---

### 第5章：运动学建模与仿真

---

### ### 13. 差速运动学模型推导

**从轮速到车速——建立物理直觉**

差速AGV有两个独立驱动的轮子，机器人中心的运动是左右两轮的"综合结果"：

- **线速度**（前进速度）：两轮速度取平均 $v = \frac{v_L + v_R}{2}$
  - 直觉：如果两轮都跑5m/s，那机器人中心也跑5m/s
  - 如果左轮5、右轮3，那中心跑4（偏向慢的一侧）

- **角速度**（转弯速度）：两轮速度差除以轮距 $\omega = \frac{v_R - v_L}{L}$
  - 直觉：差距越大转得越快；轮距越宽越"钝"（同样轮速差下转角更小）
  - 符号约定：右轮快于左轮 → AGV向左转 → $\omega$ 为正（逆时针）

**从车体速度到全局位姿**

在机器人自身坐标系下，线速度方向始终是机器人正前方。但在全局（世界）坐标系下，机器人的朝向 $\theta$ 在不断变化，因此：

$$\begin{cases}
\dot{x} = v \cdot \cos\theta \\
\dot{y} = v \cdot \sin\theta \\
\dot{\theta} = \omega
\end{cases}$$

为什么有 $\cos\theta$ 和 $\sin\theta$？因为速度 $v$ 是沿机器人正前方的，需要分解到全局 $X$ 轴和 $Y$ 轴：

- 如果机器人朝正前方（$\theta = 0°$）：$\dot{x} = v$，$\dot{y} = 0$（只往前，不左右移）
- 如果机器人朝右（$\theta = 90°$）：$\dot{x} = 0$，$\dot{y} = v$（只往右）
- 如果机器人朝斜45°：$\dot{x} = v \times 0.707$，$\dot{y} = v \times 0.707$（均分）

这就是差速驱动机器人的**运动学模型**——它描述了"车轮怎么转"和"机器人怎么动"之间的数学关系。

**轮角速度公式**（从车体速度到轮速的逆运动学）：

$$\omega_R = \frac{2v + \omega L}{2r}, \quad \omega_L = \frac{2v - \omega L}{2r}$$

**仿真参数**：初始位姿 $(0,0,0)$，轮半径 $r=0.09$ m，轮距 $L=0.52$ m，积分步长 0.01 s，总仿真时间 20 s。

**更严谨的推导**（用ICR——瞬时旋转中心）：

> **口语版**：想象你在操场上推一个转盘，转盘绕着中间的柱子转。不管转盘上哪个点，都绕着同一个柱子做圆周运动——这个柱子就是"瞬时旋转中心"（ICR）。差速 AGV 在转弯的每一瞬间，左右轮也在绕同一个 ICR 转，只是各自转的圆弧半径不同（外轮转大圈、内轮转小圈）。

差速AGV的左右轮绕同一个瞬时旋转中心（ICR）做圆周运动：

$$v_L = \omega \cdot (R - L/2)$$
$$v_R = \omega \cdot (R + L/2)$$

两式相加得 $v_L + v_R = 2\omega R = 2v$，即 $v = (v_L + v_R)/2$
两式相减得 $v_R - v_L = \omega L$，即 $\omega = (v_R - v_L)/L$

---

### ### 14. 四种典型轨迹的物理含义

**1. 直线轨迹**：$v = 0.45$ m/s，$\omega = 0$

最简单的运动模式。左右轮等速，机器人笔直前进。20 s 内累计路径长度约 9.0 m，终点航向保持 0°。仿真中验证的是"机器人能否稳定保持一条直线"——实际中由于轮径微小差异、地面不平、电机特性不对称等原因，纯开环直线很难走好，需要PID闭环来纠正偏航。

**2. 圆弧轨迹**：$v = 0.35$ m/s，$\omega = 0.45$ rad/s

左右轮保持固定的速度差，机器人以恒定曲率走圆弧。曲率 $\kappa = \omega / v = 1.286$ m⁻¹。20 s 内路径长约 7.0 m，终点航向约 155.7°。验证的是"机器人能否精确跟踪给定曲率"。

**3. S形轨迹**：$v = 0.40$ m/s，$\omega = 0.6\sin(0.5t)$

机器人交替左右转向，走出一条S形曲线。最大曲率约 1.5 m⁻¹，路径长约 8.0 m。S形轨迹的特点是曲率连续变化，验证的是"机器人在曲率连续变化时能否平滑跟随"。

**4. 8字形轨迹**：$v = 0.38$ m/s，$\omega = 0.7\sin(0.7t)$

两个S形组成一个8字。最大曲率约 1.842 m⁻¹，路径长约 7.6 m。8字形在有限区域内实现了连续、多方向的复杂运动，用以验证"机器人在持续动态变化中的综合跟踪能力"。

**曲率 $\kappa = \omega / v$ 的含义**

> **口语版**：曲率就是"弯的程度"。$\kappa = 0$ 是走直线，$\kappa$ 越大弯越急。反过来想：曲率的倒数就是转弯半径——$\kappa = 1$ 意味着半径 1 米的小圈，$\kappa = 0.1$ 意味着半径 10 米的大圈。

曲率描述了一条曲线"弯曲的程度"：
- $\kappa = 0$：直线（不弯曲/半径无穷大）
- $\kappa = 0.1 \text{m}^{-1}$：半径10m的圆弧（缓弯）
- $\kappa = 1.0 \text{m}^{-1}$：半径1m的圆弧（急弯）

对AGV来说，曲率受限于：
- 最大轮速差（$\omega_{max} = (v_{R,max} - 0)/L$）
- 线速度（速度越快，能实现的最大曲率越小——急转弯必须减速）

---

### ### 15. Hybrid A\* 算法原理

**与标准A\*的核心区别**

标准A\*的状态空间是离散的栅格坐标 $(x, y)$，每个栅格有8个邻域（上下左右+四对角）。搜索过程是"从这个格子到哪个邻居格子"。

Hybrid A\*的状态空间是连续的三维 $(x, y, \theta)$：
- $x, y$ 仍是位置，但取值是**连续值**（不像A\*那样被限制在栅格中心）
- $\theta$ 是航向角，也是连续值（通常离散化为若干档，如72档即每5°一档）

**运动基元替代栅格邻域**

标准A\*从当前栅格扩展到相邻栅格（8个方向），路径是折线。

> **口语版**：标准 A\* 就像在方格纸上走路——只能走上下左右和对角线，走出来的路是锯齿形的。Hybrid A\* 就像在真实马路上开车——你可以左转、右转、直行，走出来的路是圆滑的弧线。

Hybrid A\*从当前状态 $(x, y, \theta)$ 出发，用**运动基元（Motion Primitives）**作为扩展步骤。每个运动基元是一小段满足运动学约束的路径：
- 左转弧（不同曲率）
- 右转弧（不同曲率）
- 直线前进
- 直线后退（如果支持）

本设计中选用了 5 种离散曲率 $\kappa \in \{-1.11, -0.52, 0, 0.52, 1.11\}$ m⁻¹（分别对应转弯半径 0.90 m、1.92 m、∞、1.92 m、0.90 m）× **2个方向（前进/后退）** = **10种运动基元**。每个基元的步长取 $d = 0.5$ m，经运动学积分得到新节点位姿。仿真地图为 10 m × 8 m 的仓储环境，栅格分辨率 0.2 m，包含 5 个矩形货架障碍物。

**为什么规划路径"天然满足转弯半径约束"？**

因为每一步扩展用的都是实际可行的运动基元（由差速运动学模型生成的圆弧或直线），所以最终拼接起来的路径在每一步都是车辆实际能走的。这与A\*先规划栅格路径、后做平滑处理的策略有本质区别——A\*后处理平滑可能把一条原本安全的路径平滑到障碍物上去。

**代价函数 $f = g + h$**

- $g$（已走代价）：从起点到当前节点的实际代价。论文中包含：路径长度 + **转弯惩罚**（频繁转弯代价高，引导路径平滑）+ **倒车惩罚**（倒车比前进代价高，优先前进行驶）
- $h$（启发式代价）：从当前节点到终点的估计距离。Hybrid A\* 通常使用两种启发式的最大值：
  - 忽略障碍物的最短路径（Dijkstra启发式）：保证最优性
  - 忽略运动学约束但考虑障碍物的最短路径（A\*启发式）：保证可行性
  - 取 $\max(h_1, h_2)$ 既能保证找到路径（admissible），又能有效引导搜索方向

**论文仿真结果**：搜索在第 3134 次迭代时找到可行路径，路径总长 11.04 m，25 个节点，平均间距 0.46 m。地图为 10 m × 8 m，栅格分辨率 0.2 m，5 个矩形货架障碍物。起点 (1.0, 1.0) 航向 0°，终点 (9.0, 7.0) 航向 90°。

---

### ### 16. 红外循迹PID

**5路传感器阵列布局**

5个TCRT5000传感器并排安装在AGV底盘前端、驱动轮轴线前方 80 mm 处，间距 40 mm，总覆盖宽度 160 mm：

```
    S0   S1   S2   S3   S4
    |     |     |     |     |
  -80mm -40mm  0  +40mm +80mm
  左侧  左中  中心  右中  右侧
```

各传感器相对车体中心线的横向偏移量分别为 −80、−40、0、+40、+80 mm。底盘下方的地面上有一条黑色（或深色）循迹线，宽度约 20-30 mm。AGV的任务是让中间传感器S2始终对准循迹线。

**加权平均法计算横向偏移**

每个传感器返回一个模拟值（或阈值化后的二值），反映其下方的"黑度"：

- 如果S2读到的黑色值最大 → 小车正对循迹线 → 偏移为0
- 如果S3读到的黑色值最大 → 小车偏左（线在传感器阵列的右侧）→ 偏移为正
- 如果S1读到的黑色值最大 → 小车偏右（线在传感器阵列的左侧）→ 偏移为负

加权平均公式：
$$e = \frac{\sum_{i=0}^{4} w_i \cdot s_i}{\sum_{i=0}^{4} s_i}$$

其中 $w_i$ 是每个传感器的位置权重（如 -2, -1, 0, 1, 2），$s_i$ 是传感器读数。

实际上这计算的是循迹线的**重心位置**——线偏左重心为负，线在中间重心为0，线偏右重心为正。

**PID将偏移映射为角速度指令**

$$\omega = K_p \cdot e + K_i \cdot \int e\,\mathrm{d}t + K_d \cdot \frac{\mathrm{d}e}{\mathrm{d}t}$$

输出 $\omega$ 是角速度修正量，经差速运动学转换为左右轮转速差，实现纠偏。角速度限幅为 ±1.5 rad/s，小车标称行驶速度为 0.3 m/s。

**三个参数的物理含义**（循迹PID：$K_p=3.0, K_i=0.08, K_d=1.0$）：
- $K_p = 3.0$：偏移1个权重单位对应角速度修正3 rad/s——响应够快，但单独使用会有静差
- $K_i = 0.08$：小时候走偏的"历史账"慢慢还清——消除稳态偏移
- $K_d = 1.0$：预测偏移趋势，提前"收油"——防止过冲和振荡

三个参数是经过仿真反复调试得到的，不是随便选的。调参的基本逻辑是：先调Kp到快但不振荡，再加Kd抑制过冲，最后加少量Ki消除静差。

**循迹仿真结果**：RMS 横向误差 1.5 cm，最大横向误差 6.8 cm，仿真时长 36.2 s。最大横向误差远在传感器覆盖范围（±80 mm）内，表明传感器布局具有充足的检测裕量。

---

### 第6章：PID控制算法

---

### ### 17. PID三个环节的直观理解

**用"开车跟车"比喻PID**

想象你正在高速公路上跟着前车，你的目标是和前车保持50米距离。

- **P（比例——看现在）**：你发现和前车距离变成了30米（近了20米），你**立刻松油门减速**。距离误差越大，你动作幅度越大。但如果你只靠P，最终你会稳定在和前车距离35米的位置——有15米的**稳态误差**（因为距离35米时你的减速意愿刚好和车速平衡，不再继续调整）。

- **I（积分——记过去）**：你注意到已经和前车距离35米好一会儿了（虽然误差不大但持续存在），你心里开始"累积不满"——"都快10秒了还差15米，我再减一点速"。随着时间推移，累积的不满足够大，你终于继续减速直到距离回到50米。I消除了P留下的稳态误差。

- **D（微分——猜未来）**：你发现前车突然急刹车，距离正在**快速缩小**（误差变化率很大），虽然当前误差还不大，但你预感到马上会很危险，于是**提前猛踩刹车**。D对变化趋势敏感，帮助你"提前反应"。

**一句话总结**：
- P说："现在错了，要纠正！"（快速响应，但容易留尾巴）
- I说："错了这么久还没改过来，再使劲！"（彻底消灭尾巴，但可能用力过猛）
- D说："情况在恶化，赶紧收手！"（防止过冲，但对噪声敏感）

---

### ### 18. 双环PID架构

**为什么需要双环？**

> **口语版**：想象你开车去一个地方。外环是"导航"——告诉你"前方 500 米右转"；内环是"你的手脚"——控制方向盘和油门让车实际转过去。如果只有导航没有手脚配合，你知道该转但转不过去；如果只有手脚没有导航，你转得很精准但不知道往哪转。双环就是把"决策"和"执行"分开，各管各的。

单环PID（直接根据位置误差控制电机转速）的问题是：电机有自己的动态特性（惯性、摩擦、反电动势），位置环输出的指令到了电机执行层面会有延迟和误差。

双环架构将控制分成两层：

**外环——位姿环（Position & Orientation Loop）**

输入：期望位姿 $(x_{ref}, y_{ref}, \theta_{ref})$ 与当前位姿的误差
输出：期望线速度 $v_{cmd}$ 和期望角速度 $\omega_{cmd}$

工作频率：较低（如50Hz），因为位置变化相对慢

外环的职责是回答："我应该往哪儿走、走多快、转多快？"

$$\begin{bmatrix} v_{cmd} \\ \omega_{cmd} \end{bmatrix} = \begin{bmatrix} K_{p,v} & 0 & 0 \\ 0 & K_{p,\omega} & 0 \end{bmatrix} \begin{bmatrix} e_x \\ e_y \\ e_\theta \end{bmatrix}$$

**内环——轮速环（Wheel Speed Loop）**

输入：外环输出的 $v_{cmd}$ 和 $\omega_{cmd}$（转化为左右轮期望转速 $n_{L,ref}$ 和 $n_{R,ref}$）
输出：电机PWM控制信号

工作频率：较高（如200-250Hz），因为转速变化快

内环采用**PI控制**而非PID的原因是：速度信号本身就含有高频噪声（编码器量化噪声、机械振动），微分D会对噪声放大，导致控制信号抖动甚至电机啸叫。

$$u_L = K_{p}^{v} \cdot e_{\omega L} + K_{i}^{v} \cdot \int e_{\omega L} \, dt$$

具体参数：位姿环 $K_p=3.0, K_i=0.2, K_d=0.4$；轮速环 $K_p=17.0, K_i=103.0$（不用 D，因为编码器噪声会被 D 放大）。

**为什么内环频率要3-5倍于外环？**

控制理论中的"时间尺度分离"原则：
- 内环必须足够快，才能在外环发出新指令之前就完成上一次指令的跟踪
- 如果内环和外环频率相近，两个环会"打架"——外环看到速度还没跟上就继续加大指令，导致过冲
- 3-5倍的频率差距确保了内环对外环"如影随形"

**比喻**：外环是"指挥官"（每20ms发一次命令），内环是"士兵"（每5ms执行一次调整）。指挥官不需要知道士兵具体怎么跑的，只要下一次检查时位置对了就行。

---

### ### 19. 积分饱和与抗饱和措施

**什么是积分饱和？**

PID中积分项是对历史误差的不断累加。当系统出现"想做到但做不到"的情况时——比如期望速度指令是0.5m/s，但电机已经满功率输出也只能跑到0.3m/s（因为电池电压低或地面阻力大）——误差始终消除不了，积分项就会**一直累加**，变得非常大。

当障碍消除后（比如AGV驶出上坡路段），巨大的积分项需要很长时间才能被"反向误差"抵消。在这期间，系统会出现大幅过冲、振荡甚至不稳定。

形象比喻：像考试前攒了一学期的"负罪感"（积分），虽然最后一周开始复习了（误差开始减小），但负罪感不会立刻消失，还会驱使你继续"用力过猛"。

**抗饱和措施一：积分分离（Integral Separation）**

> **口语版**：就像你发现离目的地还很远（误差大），这时候猛踩油门就行了（P 项够用），不需要把过去所有"迟到的账"都翻出来算（I 项别掺和）。只有快到了（误差小），才需要慢慢调整消除最后那点偏差。

思想：误差很大的时候，说明P项已经足够驱动系统了，I项不要掺和。

$$u(k) = K_p e(k) + \beta \cdot K_i \sum e(j) \Delta t + K_d \frac{e(k)-e(k-1)}{\Delta t}$$

$$\beta = \begin{cases} 1 & \text{if } |e(k)| \leq \varepsilon \\ 0 & \text{if } |e(k)| > \varepsilon \end{cases}$$

当误差绝对值大于阈值 $\varepsilon$ 时，清零积分作用（$\beta = 0$）；误差进入$\varepsilon$范围内时，才启用积分来消除静差。

**论文中的具体参数**：积分分离阈值 $|e| > 8.0$ rad/s 时清零积分项；轮速 PI 输出电压限幅为 ±12V。

**离散 PID 公式**（位置式，控制周期 $T_s = 5$ ms）：

$$u(k) = K_p e(k) + K_i T_s \sum_{j=0}^{k} e(j) + \frac{K_d}{T_s}[e(k) - e(k-1)]$$

> **口语版**：这个公式看起来吓人，其实就是三句话——P 说"现在偏多少就补多少"，I 说"把过去所有偏差加起来一起算账"，D 说"看看偏差变化快不快，快的话提前踩刹车"。$T_s = 5$ ms 意思是每 5 毫秒算一次、调一次。

**电机模型参数**：机电时间常数 $\tau = 0.06$ s，电机增益 $K_m = 0.33$ (rad/s)/V（由 $K_e = 8$ V/krpm、减速比 $i=40$ 推算：$K_m = \frac{1000 \times 2\pi/60}{K_e \cdot i}$）。

> **口语版**：$\tau = 0.06$ s 是电机的"反应时间"——给它一个指令，它大约 0.06 秒后就能跟上（就像你踩油门，车不会瞬间加速，有个延迟）。$K_m = 0.33$ 意思是每给 1V 电压，电机转速增加 0.33 rad/s——这是电机的"脾气"，有的灵敏有的迟钝。

**抗饱和措施二：遇限削弱积分（Clamping）**

> **口语版**：你踩油门已经踩到底了（输出到上限），但车还是不够快（误差还在往一个方向走）。这时候继续"心里着急"（积分累加）没意义——反正油门踩到底了，再着急也加不了速。所以停止累积"着急"，等油门有余量了再继续。

思想：如果控制输出已经达到上限（如PWM已经100%），而且误差符号和控制输出符号一致（说明在"继续加力"的方向上），就停止积分累加。

$$\text{if } (u \geq u_{max} \text{ and } e > 0) \text{ or } (u \leq u_{min} \text{ and } e < 0):$$
$$\quad \text{暂停积分累加}$$

只有输出脱离饱和区后（即系统"有余力"调整时），积分才恢复工作。

---

### ### 20. 四个仿真工况的含义

| 仿真工况 | 输入 | 验证能力 | 对应实际场景 |
|---|---|---|---|
| 阶跃响应 | 2.5s 时施加 0.3 m/s 速度阶跃 | 速度环响应速度、超调量、稳态精度 | AGV从静止启动到巡航速度 |
| 定点镇定 | 目标位姿 (2.0, 1.0, π/4) | 位姿环收敛能力、终点精度 | AGV停在指定工位 |
| 直线跟踪 | 期望 $y=0.6$ m 的直线，速度 0.25 m/s | 直行保持、抗扰动能力 | 沿货架通道直行 |
| 圆形跟踪 | 半径 0.8 m、周期 16 s 的圆 | 曲线跟踪、动态误差 | 绕行障碍物或环岛行驶 |

**阶跃响应**是最"暴力"的测试——从静止突然要求全速（论文中为 2.5 s 时施加 0.3 m/s 阶跃），考验的是系统的响应速度和超调控制。论文结果：无超调、无明显振荡，调节时间约 0.8 s，稳态速度误差约为零。

> **口语版**：阶跃响应就像突然把油门踩到底——看车能不能在 0.8 秒内平稳加速到目标速度，而且不能"冲过头"再退回来（无超调）。如果这个测试都过不了，其他测试更别想了。

如果阶跃响应都做不好，其他工况更不可能做好。

**定点镇定**的独特之处在于：它同时要求位置收敛和航向收敛。到目标点但朝反方向是不合格的。

**直线跟踪**看似简单，实际对差速AGV来说需要持续纠正——两个轮子不可能完全一样，地面也不是绝对平整，没有闭环控制AGV会慢慢走偏。

**圆形跟踪**验证的是系统在持续动态输入（$\omega$ 恒不为零）下的表现，这对参数整定要求更高——$\omega$ 跟踪的难度通常大于 $v$ 跟踪。

---

### ### 21. 仿真结果解读

**定点终点误差 2.2 cm，航向偏差 −0.89° 代表什么精度？**

目标位姿为 (2.0, 1.0, π/4)，终点位置误差 (0.022, −0.007) m，航向误差 −0.89°。

- 2.2 cm 的定位精度意味着 AGV 能停在一个火柴盒大小的区域内
- 对于仓储场景（货架间距通常在 10 cm 以上），这个精度完全足够
- 航向偏差 <1° 意味着机器人基本正对目标方向，不会出现"停正了但歪着头"的情况
- 运动过程分两阶段：先以前进转向方式朝目标点运动，距离缩小至 8 cm 以下后转为原地姿态微调

**圆形跟踪 RMSE 的含义**

| 指标 | 数值 | 含义 |
|---|---|---|
| 线速度 RMSE | 0.0086 m/s | 期望速度 ~0.31 m/s 时，误差约 2.8% |
| 角速度 RMSE | 0.0031 rad/s ≈ 0.18°/s | 转弯时角速度误差极小 |
| 轨迹圆度 RMSE | 0.020 m | 实际轨迹与参考圆的径向偏差约 2 cm |

$$\text{RMSE} = \sqrt{\frac{1}{N}\sum_{i=1}^{N}(x_{actual,i} - x_{ref,i})^2}$$

**直线跟踪**：角速度 RMSE 为 0.0023 rad/s，左右轮速在稳态下保持一致，航向角始终维持在 0° 附近。

**通俗总结**：仿真结果表明，所设计的双环 PID 控制器在速度跟踪和位姿镇定两个维度都达到了实用级的精度。定点位置误差 2.2 cm、航向误差 <1° 在日常仓储作业中完全可以接受；连续轨迹跟踪的线速度和角速度 RMSE 均在 0.01 m/s 和 0.005 rad/s 量级，表明控制器具有良好的动态响应能力。

---

## 二、答辩常见问题与标准答案

---

### A. 研究背景类

---

**Q0：你为什么选这个课题？国内外研究现状如何？**

**A：**

**背景**：2024 年我国网络零售额 15.5 万亿元，连续 12 年全球最大。电商增长使仓储物流成为效率瓶颈，AGV/AMR 行业规模从 2019 年 48 亿增至 2024 年 95 亿，AMR 年增长率超 30%。

**国外**：亚马逊 Kiva 开创"货架到人"模式，Fetch Robotics/Locus Robotics 用激光 SLAM 实现无标记导航，Magazino TORU 实现视觉抓取单品，波士顿动力展示复杂地形适应能力。

**国内**：京东"地狼"AGV、菜鸟"小蛮驴"、海康威视/旷视/快仓形成成熟产品线。技术从磁条/二维码迭代到激光/视觉 SLAM。

**本文切入点**：针对中小型仓储场景中兼具举升功能与自主导航能力的紧凑型机器人，系统性工程研究仍不充分。本文以举升式自主搬运机器人为对象，围绕总体方案、机械结构、电气系统、运动学建模与运动控制展开研究。

---

### B. 方案选择类

---

**Q1：为什么用差速驱动而不用麦克纳姆轮？**

**A：** 先说结论：差速驱动在承载能力、可靠性、成本三个仓储AGV的核心指标上更优。

1. **承载能力**：麦克纳姆轮的辊子是薄弱环节，50kg载重下辊子磨损严重，寿命远低于标准橡胶轮。差速驱动用的是实心聚氨酯轮，承载50kg绰绰有余。
2. **可靠性**：麦克纳姆轮需要四个轮子精确协同才能实现期望运动，任何一个轮子打滑或辊子卡死都会导致运动偏差。差速驱动只控制两个轮子，失效概率更低。
3. **是否需要全向移动**：仓储AGV的主要运动是沿通道直行+在工位原地转向。差速驱动（可原地旋转）完全能满足，横向平移能力并非刚需。
4. **成本对比**：4个麦克纳姆轮（约2000-3000元）+ 4台电机 vs 2个普通驱动轮 + 2台电机 + 2个万向轮（约1000元），差速方案成本约为全向方案的1/3。
5. **差速驱动的不足**：对地面平整度有要求——凹凸不平的地面可能导致从动万向轮悬空，影响行驶稳定性；差速转向过程中驱动轮与地面存在滑动摩擦，长期运行会加速轮胎磨损。

总结：对于"平整地面+高负载+成本敏感"的仓储场景，差速驱动是最务实的选择。

---

**Q2：为什么用剪叉式升降而不是液压升降？**

**A：** 先说结论：剪叉式在"小型AGV+有限高度+清洁环境"三个约束下是最优解。

1. **液压的固有缺陷**：需要液压油箱、油泵、油管、液压缸，系统复杂，体积庞大。小型AGV（车体约800×600mm）根本没有空间容纳。
2. **泄漏风险**：液压油泄漏会污染仓储环境（尤其食品、医药仓库不可接受），而剪叉式纯机械结构，没有液体。
3. **维护性**：液压系统需要定期更换液压油、检查密封件，维护成本高。剪叉式只需定期润滑销轴。
4. **位置控制精度**：液压缸的位置伺服控制需要比例阀/伺服阀，成本高。电动推杆驱动剪叉式，通过电机编码器可精确定位升降高度。
5. **能量效率**：剪叉式只在升降时消耗电能，停止时电动推杆自锁，不耗电。

总结：剪叉式结构简单、维护方便、成本低、适合电动化，是小型仓储AGV的标配方案。

---

**Q3：为什么用STM32而不用PLC？工业场景不都是用PLC吗？**

**A：** 先说结论：移动平台和固定工位是不同的设计逻辑。

1. **体积和供电**：PLC需要220V交流供电（或24V大功率直流），体积至少20×10×10cm。AGV是电池供电（24V直流）、空间紧凑的移动平台，PLC根本塞不进去。
2. **成本**：一台入门级PLC（如西门子S7-1200）约1500-3000元，STM32F103C8T6约30元，价格差50-100倍。
3. **实时性**：PLC的扫描周期通常是1-10ms，STM32的定时器中断可达微秒级。对于需要高频读取编码器脉冲（10000脉冲/转，最高转速3000r/min对应500kHz脉冲频率）的控制任务，PLC的扫描周期可能不够。
4. **功耗**：PLC功耗通常在10-50W，STM32功耗<1W。电池供电的AGV对功耗极其敏感。
5. **两者不矛盾**：实际工业场景中，AGV的单片机负责底层运动控制，通过通信（如CAN/RS485）与上层PLC或上位机交互——两者是互补关系，而非替代关系。

---

**Q4：为什么用PID而不用模糊控制或MPC？PID是不是太"low"了？**

**A：** 先说结论：PID是工业控制的"常青树"，不是因为low，而是因为够用且可靠。

1. **够用原则**：差速AGV的速度—PWM关系近似线性，系统动态特性不复杂。PID对这类系统的控制效果已经很好（仿真中RMSE<0.01m/s证明了这一点）。
2. **调参可解释性**：PID三个参数各有明确的物理含义（P响应速度、I消除静差、D抑制振荡），出了问题容易排查。模糊控制的规则库不透明，出了问题很难定位是哪个规则导致的。
3. **稳定性可证明**：PID控制的稳定性有成熟的理论保证（根轨迹、频域分析）。模糊控制的稳定性分析仍然是学术界的研究课题。
4. **计算资源**：PID只需要3次乘法和2次加法，STM32轻松胜任。MPC需要在线求解优化问题，运算量是PID的数百倍。
5. **模糊控制和MPC在什么场景下更有优势？** 当系统非线性强（如倒立摆）、约束复杂（如多轴机械臂避障）、模型时变严重时，PID确实不够用。但差速AGV不属于这些场景。

总结：工程中选方案不是选"最先进"的，而是选"最适合"的。

---

**Q5：为什么用Hybrid A\*而不用标准A\*？标准A\*不是也能用吗？**

**A：** 先说结论：标准A\*规划的路径是几何可行但物理不可行的折线，Hybrid A\*规划的路径同时满足几何和物理约束。

1. **运动学约束**：标准A\*在栅格图上搜索，只能走8个方向（栅格边+对角线），生成的路径是锯齿折线。AGV实际执行时需要频繁在折点处减速转向，效率低且不流畅。
2. **Hybrid A\*的优势**：每个扩展步骤都是满足差速运动学约束的圆弧或直线，拼接起来的路径AGV可以直接执行，无需后处理平滑。
3. **状态空间的维度**：标准A\*是2D搜索$(x,y)$，Hybrid A\*是3D搜索$(x,y,\theta)$。多出来的$\theta$维度确保了AGV的航向也是连续的——在同一个$(x,y)$位置，航向不同代表不同的状态。
4. **代价合理**：Hybrid A\*的计算量确实大于标准A\*（3D搜索 vs 2D搜索），但对于AGV路径规划这种离线或准在线任务来说完全可以接受。

---

### C. 原理深挖类

---

**Q6：差速运动学中 $v = (v_L + v_R)/2$ 和 $\omega = (v_R - v_L)/L$ 是怎么推导出来的？**

**A：** 推导有两种方式，先说直觉再说严格推导。本设计中 $L = 0.52$ m，$r = 0.09$ m。

**直觉版**：
- 线速度：机器人中心是两轮连线的中点，速度自然就是两轮速度的平均值
- 角速度：两轮速度差越大转得越快，除以轮距是为了把"速度差"转化为"角速度"的量纲

**严格版（用瞬时旋转中心ICR）**：
设机器人在某一瞬间绕ICR做纯旋转运动，ICR到左轮的距离为 $R - L/2$，到右轮的距离为 $R + L/2$，其中 $R$ 是转弯半径。

左轮的速度：$v_L = \omega \cdot (R - L/2)$
右轮的速度：$v_R = \omega \cdot (R + L/2)$

相加：$v_L + v_R = 2\omega R = 2v$ → $v = (v_L + v_R)/2$
相减：$v_R - v_L = \omega L$ → $\omega = (v_R - v_L)/L$

**轮角速度公式**（用于仿真执行层输入）：
$$\omega_R = \frac{2v + \omega L}{2r}, \quad \omega_L = \frac{2v - \omega L}{2r}$$

这里假设了左右轮在同一时刻绕同一个ICR旋转（刚体运动的约束），这是一个基本合理的假设（轮胎与地面有足够摩擦力的情况下）。

---

**Q7：曲率 $\kappa = \omega / v$ 的物理含义是什么？为什么急转弯必须减速？**

**A：** 先说概念再说应用。

曲率 $\kappa$ 是曲线弯曲程度的度量，单位是 $\text{m}^{-1}$。$\kappa = 0$ 是直线，$\kappa$ 越大弯越急。$\kappa = 1/\text{转弯半径}$。

从 $\omega = \kappa \cdot v$ 可以看出：
- 给定曲率 $\kappa$，速度 $v$ 越小，需要的角速度 $\omega$ 也越小——**慢速过弯更容易**
- 给定最大角速度 $\omega_{max}$（由电机最大转速差决定），速度 $v$ 越大，能实现的最大曲率就越小——**速度快了只能走缓弯**

这就是为什么急转弯必须减速的数学原因：$\kappa_{max} = \omega_{max} / v$。当 $v$ 增大时，$\kappa_{max}$ 减小。

还有一个物理约束：离心力 $F_c = m \cdot v^2 \cdot \kappa = m \cdot v \cdot \omega$。速度越高、曲率越大，离心力越大，货物可能侧滑甚至AGV倾覆。

---

**Q8：什么是M法测速？为什么低速时误差大？**

**A：**

**M法（测频法）**：在固定时间 $T$ 内统计编码器脉冲数 $M$，速度 $n = M / (P \times T)$。

**低速误差大的原因**——量化误差：
- 假设 $T = 10\text{ms}$，编码器10000脉冲/转
- 转速3000r/min → 每周期500个脉冲 → 量化误差约0.2%
- 转速10r/min → 每周期约1.67个脉冲 → 实测可能是1个或2个 → **量化误差高达50%以上**

这就像用一把最小刻度1mm的尺子去量0.1mm的东西——根本量不出来。

**解决方案**：
- **T法（测周法）**：低速时改为测量相邻两个脉冲之间的时间间隔，适用于低速
- **M/T法**：同时测量脉冲数和时间，综合M法和T法的优点，全速段精度都好。本设计采用的就是M/T法

---

**Q9：编码器四倍频是怎么实现的？为什么是4倍而不是2倍或8倍？**

**A：**

**实现原理**：增量式编码器输出A、B两相方波，相位差90°（正交信号）。STM32定时器的编码器模式会检测两路信号的**所有边沿**：
- A相上升沿
- A相下降沿
- B相上升沿
- B相下降沿

每个边沿触发一次计数，一个完整编码器周期内有4个边沿，所以是"4倍频"。

**为什么是4倍？** 因为两路正交信号在一个周期内恰好产生4个不同的边沿——这是正交编码的物理特性决定的，不是可以随意选择的。8倍频只能通过更高分辨率的编码器（如5000P/R代替2500P/R）或者插值算法来实现，但硬件只能做到4倍。

**实现不需要CPU参与**：这是定时器的纯硬件功能——编码器信号直接连接到定时器的CH1和CH2通道，定时器在编码器模式下硬件自动计数，CPU只需要定期读取CNT寄存器。

> **口语版**：这就像超市门口的自动计数器——人走过去它自己数，不需要收银员盯着看。CPU 只需要偶尔看一眼"数到多少了"就行。

---

**Q10：航位推算为什么会有累积误差？怎么解决？**

**A：**

**误差来源**：
1. **车轮打滑**（最主要）：编码器测的是轮子转动量，但如果轮子空转（加速过猛或地面有油渍），编码器会"误以为"AGV在移动
2. **轮径不一致**：两个驱动轮磨损程度不同，直径有微小差异，导致即使电机转速一致也会走偏
3. **轮距测量误差**：$L$ 的实际值和标称值有偏差，导致角速度估计不准确
4. **离散化误差**：速度积分到位置时使用零阶保持近似，高速转弯时误差较大

**为什么是"累积"的？** 位姿更新是递推式的：$x_{k+1} = x_k + \Delta s \cdot \cos\theta_k$。当前步的误差会传递到下一步，逐级放大。

**解决方法**：
1. **定期绝对定位校准**：地面贴二维码（QR码），AGV经过时用摄像头读取绝对位置，重置累积误差
2. **传感器融合**：加入IMU（惯性测量单元），用陀螺仪数据辅助校正航向角（常用互补滤波或卡尔曼滤波）
3. **激光SLAM**：用激光雷达扫描环境特征进行匹配，实现不依赖地面标记的绝对定位
4. **轮速闭环+反滑移逻辑**：监测轮加速度，如果异常大则判断为打滑，降速或报警

---

### D. 数据与结果类

---

**Q11：阻力系数为什么取0.2？实际是多少？**

**A：**

阻力系数 $\mu = 0.2$ 是一个**保守设计的工程取值**，不是精确测量值。

**包含的来源**：
- 滚动摩擦（聚氨酯轮+环氧地坪）：约0.015-0.03
- 轴承摩擦：约0.01-0.02
- 地面不平度等效阻力：约0.05-0.10
- 加速惯性力折算：约0.05-0.08
- **合计（取上限）**：约0.2

**为什么保守取高？** 工程设计的铁律——"宁可有余不能不足"。如果按0.05来算，电机可能刚好够用或不够用；按0.2来算，实际工况大概率比这个好，电机就有充足的功率裕量。

实际地面的滚动摩擦系数通常在0.02-0.05之间。如果把所有附加因素都算上，实际等效阻力系数可能在0.08-0.12左右，远低于0.2——说明选型的400W电机确实有足够裕量。

---

**Q12：安全系数为什么取1.5？**

**A：**

> **口语版**：安全系数就像考试的"及格线"——你不能刚好考 60 分就满足，得留点余量。安全系数 1.5 意思是"设计能承受的力是实际受力的 1.5 倍"，留了 50% 的余量来应对意外情况（比如有人不小心多放了点货）。

安全系数 $n_s = 1.5$ 的选择参考了《机械设计手册》中关于"载荷性质+材料可靠性"的推荐值：

- 材料为 Q235 钢（塑性材料，性能稳定可预测）
- 载荷性质：静载荷为主（举升后保持，冲击不大）
- 计算精度：理论计算+手工校核互相验证，精度较好
- 推荐值：1.3–1.5

取 1.5 的原因：
1. 虽然计算较精确，但加工误差、装配间隙会改变实际受力
2. 举升过程中可能有操作不当（如超载、偏载）
3. 钢材对疲劳和应力集中仍需一定安全裕量
4. 1.5 在"安全"和"经济"之间取得了合理平衡——取 3.0 太保守（材料浪费），取 1.2 太激进（裕量不足）

---

**Q13：仿真中定点终点误差 2.2 cm，实际中够用吗？**

**A：** 够用，但要理解仿真和实际的差距。

**仿真场景下**：目标位姿 (2.0, 1.0, π/4)，终点位置误差 (0.022, −0.007) m，航向误差 −0.89°。运动分两阶段：先朝目标点运动，距离 8 cm 以内后转为原地姿态微调。仓储货架的定位精度通常要求 5-10 cm 即可，2.2 cm 远优于需求。

**实际中会恶化多少？** 仿真没有考虑：
- 地面不平度造成的轮子滑移
- 轮径磨损导致的模型参数漂移
- 编码器分辨率在实际转速下的表现
- 电池电压波动对电机转矩的影响

合理估计：实际误差可能会放大到 5-8 cm。但即使如此，仍能满足仓储场景的需求。如果引入二维码校准（每隔 2-3 m 贴一个码），实际误差可以降至 1-2 cm。

**答辩时如果被追问**："目前只有仿真结果，缺乏实验验证，这是本文的一个不足。后续制作实物样机或缩小比例原型是完善工作的方向。"

---

**Q14：仿真中的 RMSE 指标是怎么计算的？代表什么？**

**A：**

$$\text{RMSE} = \sqrt{\frac{1}{N}\sum_{i=1}^{N}(x_i - x_{ref,i})^2}$$

RMSE 是一种衡量跟踪误差整体水平的统计量，平方后再开方保证正负误差不会互相抵消。

> **口语版**：RMSE 就是"平均偏差"。如果你开车走直线，有时偏左 1 cm 有时偏右 1 cm，RMSE 就是 1 cm——它不管你是偏左还是偏右，只管你偏了多少。

**圆形跟踪结果**（最能体现连续跟踪能力的工况）：
- 线速度 RMSE = 0.0086 m/s：期望速度约 0.31 m/s 时，误差约 2.8%
- 角速度 RMSE = 0.0031 rad/s ≈ 0.18°/s：转弯时角速度误差极小
- 轨迹圆度 RMSE = 0.020 m：实际轨迹与参考圆的径向偏差约 2 cm

**直线跟踪**：角速度 RMSE = 0.0023 rad/s，航向角始终维持在 0° 附近。

**阶跃响应**：0.3 m/s 阶跃指令下，速度响应无超调、无明显振荡，调节时间约 0.8 s，稳态速度误差约为零。

---

**Q15：仿真结果和实际能差多少？为什么不做实物实验？**

**A：** 诚实回答——这是本科论文的常见短板。

**仿真vs实际的差距来源**：
1. 仿真中轮子与地面是纯滚动（无滑移），实际存在滑移
2. 仿真中传感器数据是理想值（无噪声、无延迟），实际有噪声和延迟
3. 仿真中电机模型是简化的（一阶惯性），实际电机有死区、摩擦非线性
4. 加工精度、装配误差在仿真中不存在

**为什么没做实物**：
1. 整套硬件（伺服电机×2+驱动器×2+电动推杆+机械加工+传感器+电池+STM32）的成本估算约5000-8000元，本科毕设经费有限
2. 机械加工周期长（需要3D打印或CNC加工零部件），时间不够
3. 仿真阶段已经完成了方案验证和参数整定，为后续的实物搭建提供了充分的理论基础

**答辩时强调**：仿真不是"偷懒"，而是实际工程的必经阶段——先仿后做、以仿导做是标准流程。此外，机械结构部分已通过 MATLAB 有限元分析对手算结果进行了数值验证（臂杆组合应力偏差 <1%），增强了校核结果的可信度。

---

**Q15b：双环PID和单环PID的对比结论是什么？内环速度闭环到底带来了多大提升？**

**A：** 在相同外环参数下，加入内环速度PI反馈后，四项工况的指标全面提升：

| 场景 | 双环PID | 单环PID | 差距 |
|---|---|---|---|
| 阶跃响应速度稳态误差 | 0.002 m/s | 0.093 m/s | 约46倍 |
| 定点镇定位置误差 | 0.020 m | 0.072 m | 3.6倍 |
| S形轨迹线速度RMSE | 0.007 m/s | 0.067 m/s | 9.6倍 |
| 圆形轨迹圆度RMSE | 0.020 m | 0.061 m | 3倍 |

**核心原因**：单环PID将速度指令直接转换为电压，缺乏对电机实际转速的闭环反馈。当加入正弦负载扰动（模拟地面摩擦变化）时，扰动完全由外环承担，导致跟踪精度下降。双环结构的内环速度PI以5 ms控制周期快速跟踪轮速指令，在电机层面及时抑制了扰动。

S形轨迹差距最大（9.6倍），因为该工况下角速度频繁变化，对速度环的动态响应要求最高，最能体现内环闭环的优势。

---

### E. 不足与改进类

---

**Q16：你的工作有什么主要局限？**

**A：** 实事求是地说，有以下局限（与论文结论§7.2对应）：

1. **缺乏实验验证**：第五章的运动学建模与仿真验证及第六章的运动控制仿真均基于MATLAB平台，没有在真实硬件上测试。电机死区、轮胎打滑、传感器噪声等实际因素未充分体现。

2. **算法对比不足**：在第五章的路径规划与循迹仿真及第六章的运动控制验证中，只给出了 Hybrid A\* + PID 方案的结果，缺乏与其他算法（如标准 A\* + 后处理平滑、RRT\* + PID）的定量横向对比。

3. **模型简化**：第五章的运动学模型是二维平面运动学模型，对动力学特性、负载变化和多传感器融合考虑不足。

4. **控制策略适应性有限**：第六章采用的经典 PID 参数固定，对动态障碍物避让、多车协同、路径在线重规划等复杂任务适应能力有限。

5. **系统集成不完善**：编码器闭环测速、多传感器融合、任务调度、无线通信等功能尚未深入展开。

---

**Q17：Hybrid A\*有没有更快的替代方案？**

**A：** 有，取决于场景需求：

1. **如果地图简单、障碍物稀疏**：直接用**杜宾斯曲线（Dubins Curve）**或**Reeds-Shepp曲线**连接起点和终点（搜都不用搜），计算极快
2. **如果追求实时性**：**状态栅格（State Lattice）**——离线预计算所有运动基元终点，在线只需查表，速度比Hybrid A\*快数倍
3. **如果地图变化频繁**：**RRT\*（Rapidly-exploring Random Tree Star）**或**Informed RRT\***——随机采样策略在大空间中搜索效率高于栅格搜索
4. **如果算力充裕（有GPU/工控机）**：基于优化的方法如**MPC路径规划**——直接求解带运动学约束的优化问题，同时得到路径和控制序列

但Hybrid A\*在"运动学约束满足+最优性+实现难度"三个维度上是最平衡的选择，特别适合本科论文的场景。

---

**Q18：PID参数能不能自适应调整？**

**A：** 可以，这就是自适应PID或自整定PID。

**为什么本设计没用自适应PID？**
1. AGV的工况相对固定（平整地面、50kg载重），PID参数整定一次后不需要频繁调整
2. 自适应增加了算法复杂度和代码量，增加了出错风险
3. 本科论文的重点是"理解PID原理并应用"，自适应PID作为扩展方向提到即可

**自适应PID的实现思路**：
- **增益调度（Gain Scheduling）**：根据不同负载（空载/满载）预先整定两组PID参数，工作时根据载重切换
- **模糊自整定**：用模糊规则在线调整Kp/Ki/Kd（"如果误差大且变化快，则增大Kp减小Ki"）
- **基于模型的自适应**：在线辨识系统参数（如转动惯量），根据辨识结果调整PID参数

---

**Q19：为什么不加IMU做航向融合？**

**A：**

**原因**：
1. **成本控制**：一个精度尚可的IMU（如MPU6050）虽然只要十几元，但IMU的陀螺仪有零偏漂移，需要设计互补滤波或卡尔曼滤波来融合编码器和IMU数据——增加了算法复杂度
2. **编码器+循迹线已经够用**：在有循迹线的场景下，红外传感器提供了绝对位置参考（线在哪机器人就在哪），航向的累积误差被循迹约束消除了
3. **仿真环境加不了IMU**：仿真是纯运动学/动力学仿真，加IMU意味着需要模拟传感器噪声模型，增加了仿真的复杂度且意义有限

**什么场景下必须加IMU？**
- 没有循迹线、全靠惯性导航（完全依赖航位推算时，IMU必不可少）
- 高速运动（>1m/s）时编码器滑移严重
- 需要检测急停/碰撞（加速度计）

---

### F. 应用场景类

---

**Q20：最大载重50kg能搬运什么类型的物料？**

**A：**

50kg的载重覆盖了仓储物流中**中小件**的大部分场景：
- **电商包裹**：单个快递包裹通常0.5-5kg，一次可搬运10-100件
- **电子元器件**：PCB板、芯片托盘等，重量轻但体积小，50kg能装很多
- **药品/医疗器械**：药盒、试剂盒等，单件几十克到几千克
- **图书/文件**：单本几百克，50kg约为100-200本书
- **食品饮料**：瓶装水（一箱约10-15kg）、调味品等

**不能搬的**：大型家电（冰箱>50kg）、整托盘货物（>100kg）、大型机械部件（>50kg且尺寸超限）。

**扩展思路**：如果增大电机功率和结构强度，载重可提升至100-200kg（对应更大尺寸的AGV）。

---

**Q21：AGV对地面有什么要求？**

**A：**

1. **平整度**：建议起伏不超过±3mm/m。差速驱动依赖两侧轮子与地面的良好接触，如果地面不平导致一侧轮子悬空，驱动和测速都会失效
2. **材质**：环氧地坪最佳（摩擦力适中、耐磨），水泥地面也可（但表面粗糙会增加滚动阻力和轮子磨损）
3. **清洁度**：无异物（螺丝、包装碎片等可能卡住万向轮）、无油渍（会导致打滑）
4. **坡度**：建议不超过2°（约3.5%）。更大坡度需要重新校核电机功率和制动能力
5. **接缝**：地面伸缩缝宽度<10mm且两侧无高差，否则万向轮会被卡住

这些都是仓储场景中通常能满足的条件（现代化仓库本身就是按这些标准建设的）。

---

**Q22：AGV能和仓储管理系统（WMS）对接吗？**

**A：** 能，但需要添加通信模块。

**当前设计的通信能力**：STM32F103C8T6有USART（串口），可以通过RS485或WiFi模块与上位机通信。

**对接架构**：
```
WMS（仓库管理系统）→ WCS（仓库控制系统）→ AGV调度系统 → 单台AGV（STM32）
```

- WMS发出"把A货架的XX货物搬到B区"的指令
- WCS将指令分解为具体的AGV任务（哪台AGV、走哪条路线）
- AGV调度系统通过WiFi将目标坐标和路径发送给AGV
- AGV执行并回传状态（位置、速度、任务进度、电池电量）

**需要补充的部分**：通信协议设计（如Modbus RTU或自定义协议）、任务队列管理、异常处理（通信断线时的安全策略）。

---

**Q23：AGV的安全性怎么保证？**

**A：**

本设计中包含以下安全措施：

1. **超声波避障**：检测前方2cm-4m范围内的障碍物，有障碍时减速或急停
2. **编码器打滑检测**：如果轮速异常增大但超声波测距没变化 → 判断为打滑 → 降速
3. **机械限位**：剪叉机构的上下极限位置设有限位开关（行程开关），防止电动推杆过行程
4. **急停按钮**：车体侧面有物理急停按钮（常闭触点），按下后切断电机电源

**可以增强的安全措施**（论文未做但实际应该加）：
- **安全触边（Bumper）**：AGV外围安装压敏安全触边，一旦碰到障碍物立即急停
- **声光报警**：运行时蜂鸣器+警示灯，提醒周围人员
- **安全PLC**：对速度进行独立监控，主控失效时安全PLC接管急停

---

### G. 技术细节类

---

**Q24：红外传感器阵列 5 路具体怎么排列的？偏移量怎么算？**

**A：**

**物理排列**：5 个 TCRT5000 并排安装在 AGV 底盘前端、驱动轮轴线前方 80 mm 处，间距 40 mm，总覆盖宽度 160 mm。各传感器相对车体中心线的横向偏移量分别为 −80、−40、0、+40、+80 mm。循迹线（黑色胶带，宽约 20–30 mm）贴在地面上。传感器模块板载 LM393 比较器，输出数字量（0/1），直接接 STM32 的 GPIO。

**偏移量计算——加权平均法**：

给每个传感器分配位置权重：S0 = −4, S1 = −2, S2 = 0, S3 = +2, S4 = +4

偏移量：
$$e = \frac{-4 \times s_0 + (-2) \times s_1 + 0 \times s_2 + 2 \times s_3 + 4 \times s_4}{s_0 + s_1 + s_2 + s_3 + s_4}$$

其中 $s_i \in \{0, 1\}$ 为传感器数字输出（1 表示检测到黑线）。$e$ 取值范围 $[-2, +2]$，负值表示 AGV 偏左，正值偏右。

**举例**：
- 所有传感器均未检测到黑线（全 0）→ 分母为 0 → 丢线，偏移量外推为上次数值的 1.5 倍，加大纠偏力度
- 只有 S2 检测到黑线 → $e = 0$（正中）
- S3 和 S4 同时检测到黑线 → $e = (2+4)/2 = +3$（线偏右，AGV 偏左，需右转修正）

---

**Q25：M/T法测速的具体计算过程是怎样的？**

**A：**

M/T法同时在一个采样周期内测量**脉冲数**和**时间**：

1. 设定一个固定的采样时间窗口 $T_c$（如10ms）
2. 在 $T_c$ 开始时记录定时器计数值
3. 检测到的第一个编码器脉冲启动高频时钟计数（如72MHz）
4. 在 $T_c$ 结束时等待下一个编码器脉冲到达后停止
5. 记录：
   - $M_1$：$T_c$ 内检测到的编码器脉冲数
   - $M_2$：高频时钟脉冲数（对应实际测量时间 $T_d = M_2 / 72\text{MHz}$）

速度：
$$n = \frac{60 \cdot M_1}{P \cdot T_d} = \frac{60 \cdot M_1 \cdot f_{clk}}{P \cdot M_2}$$

其中 $P = 10000$（四倍频后每转脉冲数），$f_{clk} = 72\text{MHz}$。

**为什么M/T法好？**
- 高速时 $M_1$ 大 → 接近M法精度（脉冲多，数得准）
- 低速时 $M_2$ 大 → 接近T法精度（时间长，量得准）
- 全速段精度均衡

> **口语版**：M/T 法就是"两手准备"——高速时靠数脉冲（M 法好使），低速时靠量时间（T 法好使），两个同时做，哪个准用哪个。就像你既带了尺子又带了秒表，量什么都够用。

---

**Q26：PID 参数是怎么调出来的？**

**A：**

本文有两套 PID 参数，分别用于不同任务：

**循迹 PID**（$K_p=3.0, K_i=0.08, Kd=1.0$）：用于红外传感器循迹，以横向偏移量为输入，输出角速度修正量。

**双环 PID**（运动控制）：
- 位姿环：$K_p=3.0, K_i=0.2, K_d=0.4$
- 轮速环：$K_p=17.0, K_i=103.0$（不用 D，因为编码器噪声会被 D 放大）

调参使用经典的 **Ziegler-Nichols 工程整定法**辅以手动微调：

1. **第一步**：置 $K_i=0, K_d=0$，逐步增大 $K_p$ 直到系统出现等幅振荡，记录临界 $K_p$ 和振荡周期 $T$
2. **第二步**：按 ZN 公式计算初始值
3. **第三步**：在仿真中运行四种工况（阶跃/定点/直线/圆），观察响应并微调
4. **第四步**：反复迭代直到各项指标满意

---

**Q27：剪叉机构最低位为什么受力最大？能从受力分析角度解释吗？**

**A：**

从受力分析角度，电动推杆提供的推力与负载之间的关系可以用虚功原理（虚位移原理）推导。由几何关系 $H = L\sin\beta + h_0$，当 $\beta$ 很小时 $\sin\beta$ 很小，臂杆轴向力 $F_{\text{arm}} = F/(4\sin\beta)$ 急剧增大。

因此角度 $\beta$ 越小，推力 $F$ 越大。在 $\beta = 9.55°$（最低位）时，$\sin\beta \approx 0.166$，臂杆轴向力约 739 N，约为最高位（$\beta = 66.75°$，$\sin\beta \approx 0.919$，$F_{arm} \approx 134$ N）时的 **5.5 倍**。

**用杠杆类比**：剪叉就像一组串联的杠杆。当臂杆近乎水平时，你是在用水平力去"撬"起竖直的负载——杠杆的机械劣势巨大。当臂杆接近45°以上时，力臂比改善，推起来就轻松多了。

---

### H. 基础概念与全局类

---

**Q28：AGV 和 AMR 到底有什么区别？你的设计算哪个？**

**A：** 简单说：AGV 靠"路上有什么"来导航，AMR 靠"自己看到什么"来导航。

| | AGV | AMR |
|---|---|---|
| 导航方式 | 磁条、二维码、激光反射板等预设标记 | 激光 SLAM、视觉 SLAM，自主建图定位 |
| 路径灵活性 | 沿固定路线走，改道需重新铺设标记 | 自主规划路径，动态避障 |
| 部署成本 | 低（硬件简单），但改布局成本高 | 高（激光雷达+工控机），但改布局零成本 |
| 适用场景 | 路线固定、环境结构化的大批量场景 | 环境动态变化、人机混行的柔性场景 |

**本文设计的定位**：导航方案采用"Hybrid A\* 全局规划 + 红外循迹局部跟踪"的两层架构，循迹线需预先铺设，属于 **AGV 范畴**。但 Hybrid A\* 提供了路径重规划能力——当仓储货架布局变化时，可基于更新后的地图自动重新规划路径，无需人工重新铺设引导标识，这点又带有 AMR 的思想。准确说是**"具备一定柔性的 AGV"**。

---

**Q29：你的 AGV 是怎么实现"自主"的？哪些环节体现自主性？**

**A：** 自主性体现在三个层次：

1. **自主决策去哪**：Hybrid A\* 根据仓储地图自动规划无碰撞路径（搜索在第 3134 次迭代找到可行路径，总长 11.04 m），不需要人工指定每一步怎么走
2. **自主沿路走**：5 路红外传感器阵列检测循迹线偏移量 → PID 控制器计算角速度修正量 → 差速执行，全过程闭环自动完成（RMS 横向误差 1.5 cm）
3. **自主保护自己**：超声波传感器检测前方障碍物（2 cm – 4 m 范围），遇到障碍减速或停车

两层架构的分工：Hybrid A\* 负责"走哪条路"（决策层），红外循迹负责"如何沿路走"（执行层）。不自主的部分：地图需要预先构建、循迹线需要预先铺设、任务指令（去哪取货）由上层的 WMS/WCS 下发。

---

**Q30：你这台 AGV 整体多重？多大尺寸？**

**A：** 从论文中可汇总如下（部分为设计估算值）：

- **整车自重**：约 200 kg（含车架、电机、减速器、电池、升降机构等）
- **额定载重**：50 kg
- **满载总质量**：约 250 kg
- **驱动轮直径**：180 mm，轮半径 $r = 0.09$ m
- **轮距**：$L = 0.52$ m（两驱动轮中心距）
- **承载平台**：660 mm × 312 mm × 3 mm（Q235 钢板）
- **升降范围**：台面距底座约 149–600 mm，行程约 452 mm
- **臂杆规格**：36 mm × 4.8 mm Q235 实心扁钢，长 600 mm
- **销轴**：直径 18 mm，45 号钢

整体属于**紧凑型**搬运 AGV，适合在标准货架通道（宽约 1.2–1.5 m）中通行。

---

**Q31：剪叉机构是单层还是多层的？为什么不用多层？**

**A：** 单层剪叉（两根等长臂杆在中点交叉铰接）。不用多层的原因：

1. **行程已经够用**：单层实现约 451 mm 升程，满足 0.45 m 设计指标
2. **多层增加复杂度**：每增加一层就多一组臂杆和铰点，增加制造成本和装配误差
3. **多层降低稳定性**：层数越多，高位时累计间隙越大，平台晃动越明显
4. **够用原则**：本设计不是高空作业平台，451 mm 对应仓储货架的底层到中层，完全覆盖目标场景

---

**Q32：整个 AGV 的电源从哪来？电池能用多久？**

**A：** 论文选用了锂离子电池组作为主电源，经 DC-DC 变换器输出不同电压等级（5V 供 STM32/传感器，48V 供伺服电机驱动器）。

续航估算思路（论文未精确计算，但可大致推算）：
- 匀速行驶功率：约 132 W（电机侧理论功率）
- 举升功率：举升一次 50 kg × 0.45 m 约需 220 J 能量，时间短、平均功率不大
- 若配 48V/20Ah 锂电池组（约 960 Wh）：纯行驶续航约 960/132 ≈ 7 小时
- 实际考虑加速、举升、待机等因素，有效工作时间约 4–6 小时

这是答辩时可说的估算逻辑，精确数据需实测。

---

**Q33：编码器 2500 P/R 是什么意思？四倍频又是什么？**

**A：**

- **2500 P/R**：Pulses per Revolution，编码器每转一圈输出 2500 个脉冲（A 相或 B 相单相计数）
- **为什么有四倍频**：A、B 两相相位差 90°，四个边沿（A 升、B 升、A 降、B 降）在一个周期内各出现一次，STM32 定时器的编码器模式对全部四个边沿计数
- **结果**：2500 × 4 = **10000 脉冲/转**
- **全硬件完成**：定时器自动计数，不消耗 CPU 时间。CPU 只需在控制周期（5 ms）到来时读一下计数器

通俗版：编码器每圈喊 2500 声"嘀"，但 STM32 能听出每声"嘀"的起和落，于是一圈数出 10000 个信号。

---

**Q34：PID 三个参数各管什么？你的参数怎么调出来的？**

**A：**

| 参数 | 作用 | 调大后的效果 | 调太大 |
|---|---|---|---|
| $K_p$ | 对当前误差即时响应 | 响应快 | 振荡、超调 |
| $K_i$ | 对历史误差累积补偿 | 消除稳态误差 | 响应慢、积分饱和 |
| $K_d$ | 对误差变化趋势预判 | 抑制超调、减小振荡 | 对噪声敏感、抖动 |

**调试方法**：先 $K_i=K_d=0$，逐步增大 $K_p$ 至系统临界振荡，记录临界 $K_p$ 和振荡周期；按 Ziegler-Nichols 公式算初始值；在 MATLAB 四种工况（阶跃/定点/直线/圆）下仿真微调，反复迭代直到各项指标满意。

**最终值**：
- 循迹 PID：$K_p=3.0, K_i=0.08, K_d=1.0$（红外循迹任务）
- 位姿环（运动控制外环）：$K_p=3.0, K_i=0.2, K_d=0.4$
- 轮速环（运动控制内环）：$K_p=17.0, K_i=103.0$（不用 D，因为编码器噪声会被 D 放大）

---

**Q35：你的 Hybrid A\* 和普通 A\* 到底差在哪？能举个具体例子吗？**

**A：**

论文中仿真地图为 10 m × 8 m 的仓储环境，栅格分辨率 0.2 m，包含 5 个矩形货架障碍物。起点 (1.0, 1.0) 航向 0°，终点 (9.0, 7.0) 航向 90°。

- **A\*** 在栅格上搜索，只能走 8 个方向，路径是锯齿折线，不满足转弯半径约束，必须后处理平滑（但平滑后可能撞到障碍物）
- **Hybrid A\*** 搜索在第 3134 次迭代时找到可行路径，路径总长 11.04 m，共 25 个节点，平均间距 0.46 m。每次扩展用圆弧或直线（5 种曲率 × 2 方向 = 10 种运动基元），路径天然满足差速运动学约束

**关键区别一句话**：A\* 规划的路线人走着没问题，但 AGV 走不了；Hybrid A\* 规划的路线 AGV 真能开。

**循迹验证**：沿规划路径铺设引导线，PID 循迹 RMS 横向误差 1.5 cm，最大横向误差 6.8 cm。

---

**Q36：你论文的最大创新点或特色是什么？**

**A：** 本科论文不要求颠覆性创新，重点在于**系统性工程实践**。本文的特色是：

1. **完整的自上而下设计链条**：总体方案→机械结构→电气系统→运动学建模→路径规划→运动控制→仿真验证，覆盖了移动机器人开发的全部关键环节
2. **举升与搬运一体化**：在差速底盘上集成剪叉式升降机构，同时解决"搬运"和"举升"两个需求，市面上多数教学/研究平台只有搬运没有举升
3. **两层导航架构**：Hybrid A\* 全局路径规划（决策层）+ 红外循迹 PID 局部跟踪（执行层），规划层可替换而执行层不变，架构清晰、可扩展
4. **理论与数值双重验证**：机械结构强度校核采用手算 + MATLAB 有限元数值验证的双重方法，臂杆组合应力偏差 <1%，增强了结果可信度

---

**Q37：如果现在重新做这个课题，你会怎么改进？**

**A：**

1. **加实物验证**：用 3D 打印 + 步进电机搭一个缩小比例原型（如 1:5），验证控制算法在真实硬件上的表现
2. **换更强的感知**：用低成本激光雷达（如 YDLIDAR X4，约 500 元）替代红外循迹，实现不依赖地面标记的 SLAM 导航
3. **引入 ROS**：将控制程序移植到 ROS（机器人操作系统），利用其成熟的导航栈（move_base、gmapping），减少从零造轮子的工作量
4. **动力学模型**：在运动学模型基础上加入动力学（惯性、摩擦、电机特性），提高仿真精度
5. **多 AGV 协同**：加入简单的多机调度逻辑（如交通规则、优先权），向实际仓储场景再靠近一步

---

**Q38：论文里仿真了四种轨迹（直线/圆/S形/8字），为什么不仿真更复杂的工况？**

**A：** 四种轨迹遵循了**从简单到复杂的递进验证逻辑**：

- 直线 → 验证基本直行能力
- 圆 → 验证稳态曲线跟踪
- S 形 → 验证曲率连续变化下的平滑跟随
- 8 字 → 验证高频换向和综合动态跟踪

这四种工况构成了一套完整的"能力测验"，类似于考驾照先考直线行驶、再考弯道、再考 S 弯、最后考综合路况。更复杂的工况（如随机障碍物、多 AGV 交互）可以由这四种基本能力组合应对，但不改变对控制器本质性能的评估。

---

**Q39：你的 AGV 设计中有哪些安全保护措施？**

**A：** 论文中涉及的安全措施：

1. **超声波避障**：HC-SR04 检测 2 cm–4 m 范围障碍，触发减速或停车
2. **编码器打滑监测**：轮加速度异常大 → 判断为打滑 → 降速，防止空转失控
3. **机械限位**：剪叉机构上下极限位置设行程开关，防止推杆过行程损坏机构
4. **急停按钮**：车体侧面物理急停（常闭触点），按下即断电机电源
5. **积分抗饱和**：遇限削弱积分 + 积分分离，防止控制器在异常工况下失控

论文中未做但实际应补充的：安全触边（接触即停）、声光报警（提醒周围人员）、电池低电量自动返航。

---

**Q40：差速驱动如果一侧轮子打滑了，AGV 会怎样？怎么办？**

**A：**

**会怎样**：编码器只测轮子转动量，测不出是否打滑。打滑侧的编码器读数偏大 → 航位推算误以为该侧走了更远 → 估算的位姿与实际偏离，AGV 走偏甚至原地打转。

**检测方法**：监测轮加速度。正常行驶时加速度有限（受电机转矩和惯性约束），打滑时轮子突然加速，加速度远超正常范围 → 触发打滑标志。

**应对策略**：
1. 降低该侧电机输出（减少打滑）
2. 短暂制动让轮子恢复附着力
3. 在航位推算中标记该时段数据不可信，待恢复正常后重新积累
4. 若有绝对定位手段（二维码、激光），用绝对位置校准重置累积误差

---

**Q41：你的设计有没有参考市面上已有的产品？**

**A：** 本文为自主设计方案，但参考了以下行业实践的方法论：

- **Kiva（Amazon Robotics）**："货架到人"理念和中央调度架构
- **极智嘉（Geek+）**：差速底盘 + 举升机构的紧凑型 AGV 布局
- **海康威视**：仓储 AMR 的传感器配置思路（红外 + 超声波低成本方案）

本文与商业产品的差异在于：商业产品用激光 SLAM + 视觉 + 工控机，成本高（单台 10–20 万）；本文以 STM32 + 红外 + 超声波的低成本方案（物料成本约 3000–5000 元）探索了"够用就好"的轻量化路径。

---

**Q42：你觉得自己论文最薄弱的地方在哪？**

**A：** 诚实回答——**缺乏实物实验验证**。

第五章的运动学建模、路径规划与循迹仿真，以及第六章的运动控制仿真，均基于 MATLAB 理想环境，没有在真实硬件上测试。仿真环境的理想假设（纯滚动无滑移、传感器无噪声无延迟、电机是完美一阶惯性环节）与实际物理世界之间存在差距。

其次是**与同类算法的定量对比不足**：第五章只给出了 Hybrid A\* + 红外循迹 PID 的结果，第六章只给出了双环 PID 的结果，没有和标准 A\* + 后处理平滑、或 RRT\* + PID 等替代方案做定量横向对比。

此外，第五章的运动学模型是二维平面模型，未考虑动力学特性；第六章的 PID 参数固定，对动态工况适应能力有限。

答辩时主动说出不足比被老师指出更好——说明你有自知之明，知道下一步该做什么。

---

## 三、考前自检清单

答辩前逐条过一遍，每一条都能用自己的话讲清楚就说明准备充分了。

- [ ] **研究背景**：能说出 AGV 市场规模（48→95亿）、AMR 增长率（>30%）、国内外代表性企业（Kiva、京东、海康等）
- [ ] **差速驱动原理**：能一句话讲清"两轮速度差产生转弯"，能写出$v$和$\omega$的公式
- [ ] **剪叉机构**：能区分臂杆夹角 $\alpha$ 和水平半角 $\beta=\alpha/2$，写出 $H=L\sin\beta+h_0$，能解释为什么最低位（$\beta=9.55°$）最危险
- [ ] **控制方案选型**：能说清为什么用STM32而不用PLC、为什么用PID而不用MPC
- [ ] **电机选型**：记得30m/min→40减速比的推导链条，知道400W有功率裕量
- [ ] **屈曲失稳**：能解释长细比$\lambda$的含义和侧向支撑的平方效应
- [ ] **编码器四倍频**：知道2500P/R→10000脉冲/转，知道是硬件自动完成的
- [ ] **航位推算**：能写出位姿递推公式，知道累积误差来自滑移
- [ ] **运动学模型**：能写出$\dot{x}=v\cos\theta$等三个方程，知道物理含义
- [ ] **Hybrid A\***：知道与A\*的核心区别是状态加$\theta$维度和运动基元
- [ ] **PID三个环节**：能用"跟车"比喻讲清P/I/D各自的作用
- [ ] **双环PID**：知道外环位姿内环轮速，内环频率3-5倍于外环
- [ ] **双环vs单环对比**：记得S形轨迹线速度RMSE差距最大（9.6倍），圆形轨迹圆度RMSE双环仅为单环的33%，能解释内环抗扰机制
- [ ] **积分饱和**：知道什么是积分饱和，能说出积分分离和遇限削弱两种方法
- [ ] **四种仿真工况**：知道阶跃/定点/直线/圆形各自验证什么能力
- [ ] **仿真结果**：记得定点误差 2.2 cm、航向误差 −0.89°、线速度 RMSE 0.0086 m/s、角速度 RMSE 0.0031 rad/s、轨迹圆度 RMSE 0.020 m
- [ ] **循迹结果**：记得 RMS 横向误差 1.5 cm、最大横向误差 6.8 cm、传感器覆盖 ±80 mm
- [ ] **论文不足**：能诚实说出缺乏实验验证，能提出改进方向
- [ ] **AGV vs AMR**：能说清两者区别，知道自己设计的定位（"具备一定柔性的 AGV"）
- [ ] **整车参数**：记得自重 200 kg、载重 50 kg、满载 250 kg、轮径 180 mm、轮距 520 mm、升程 452 mm
- [ ] **编码器基础**：能解释 2500 P/R → 10000 脉冲/转的原理
- [ ] **PID 调参**：能说清两套参数（循迹 PID 和双环 PID）的取值和各自作用
- [ ] **有限元验证**：知道论文用 MATLAB 梁单元 FEA 验证了手算结果（臂杆组合应力 5.60 MPa vs 手算 5.56 MPa，偏差 <1%）
- [ ] **两层导航架构**：能说清 Hybrid A*（全局规划/决策层）+ 红外循迹（局部跟踪/执行层）的分工
- [ ] **安全措施**：能列举论文中的 5 项安全设计
- [ ] **打滑处理**：知道打滑的危害、检测方法和应对策略
- [ ] **创新点**：能用自己的话总结论文的 3 个特色
- [ ] **改进方向**：能说出如果重做会怎么改（至少 3 条）
- [ ] **最薄弱处**：能坦然说出缺乏实物验证这个最大短板

---

> **最后叮嘱**：答辩考察的不是你"做没做出实物"，而是你"对所做工作有没有真正的理解"。把每个设计决策背后的"为什么"想清楚，把每个公式的物理含义理解透，把仿真结果能解释明白，坦然面对不足、清晰说出改进方向——这就是一篇优秀的本科毕业论文答辩。

---

*文档更新日期：2026年5月27日（同步论文结论§7.2章节引用修正）*

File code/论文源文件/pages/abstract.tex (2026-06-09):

% !Mode:: "TeX:UTF-8"

%? ************************************************************* %?
%?                                                               %?
%?                   您将在此处完成中英文摘要的填写                   %?
%?                                                               %?
%? ************************************************************* %?

% ====================== 摘要 ======================

\chapter*{\texorpdfstring{\centering \heiti \sanhao \textbf{摘\quad 要}}{摘要}}
\addcontentsline{toc}{chapter}{\texorpdfstring{\sihao{摘\qquad 要}}{摘要}}

\linespread{1.5}\selectfont
\fangsong\xiaosi

\vspace{1em}

\xfabstract{

    针对中小型仓储场景中物料搬运自动化程度不足的问题，本文设计了一款集成剪叉式举升功能的双轮差速驱动移动机器人。通过多方案对比，确定了"交流伺服电机+行星减速器"的动力方案、ARM单片机嵌入式控制系统，以及Hybrid A*全局路径规划与双环PID运动控制相配合的导航控制策略。

    升降机构运动学建模与强度校核表明，在50\,kg额定载重下，臂杆最危险工况的压弯组合应力仅为5.56\,MPa，承载平台von Mises等效应力为14.1\,MPa，均远低于Q235钢156.7\,MPa的许用应力；增设侧向支撑后，臂杆屈曲安全系数由2.54升至10.1，结构安全裕度充足。

    MATLAB控制仿真覆盖了阶跃响应、定点镇定、S形轨迹跟踪和圆形轨迹跟踪四种典型工况。定点镇定终点位置误差收敛至厘米级，航向偏差小于1$^\circ$；连续轨迹跟踪的线速度与角速度RMSE分别低于0.01\,m/s和0.005\,rad/s。路径规划方面，Hybrid A*算法在含障碍物的仓储地图上生成了长14.00\,m的无碰撞平滑路径，红外循迹PID控制器以0.58\,cm的RMS横向误差实现了对该路径的稳定跟踪。

    研究结果表明，本文所设计的机器人在结构强度、运动控制精度与路径规划可行性方面均达到预期指标，可为同类举升式仓储搬运机器人的工程研制提供参考。

}

\noindent{\heiti\xiaosi\textbf{关键词：}}
\fangsong{智能仓储移动机器人；差速驱动；路径规划；Hybrid A*；PID运动控制}

% ====================== Abstract ======================

\chapter*{}
\vspace*{-1.15cm}
{\centering\bfseries\sanhao ABSTRACT\par}
\addcontentsline{toc}{chapter}{\sihao{ABSTRACT}}
\vspace{0.5cm}

\linespread{1.5}\selectfont
\rmfamily\xiaosi

\xfenabstract{
    Aiming at the insufficient automation of material handling in small-to-medium warehouse environments, this thesis presents a dual-wheel differential-drive mobile robot with an integrated scissor-type lifting mechanism. Through comparative analysis of multiple design options, an AC servo motor with planetary reducer drive scheme, an ARM Cortex-M microcontroller-based embedded control system, and a navigation strategy combining Hybrid A* global path planning with dual-loop PID motion control are established.

    Kinematic modeling and strength verification of the lifting mechanism demonstrate that, under the rated payload of 50\,kg, the combined compressive-bending stress of the scissor arm in the worst-case condition is merely 5.56\,MPa, and the von Mises equivalent stress of the loading platform is 14.1\,MPa — both far below the 156.7\,MPa allowable stress of Q235 steel. With lateral bracing added, the buckling safety factor of the arm increases from 2.54 to 10.1, providing an ample safety margin.

    MATLAB control simulations cover four typical scenarios: step response, point stabilization, S-curve trajectory tracking, and circular trajectory tracking. The terminal positioning error in point stabilization converges to the centimeter level with heading deviation under 1$^\circ$; the RMSE of linear and angular velocities in continuous trajectory tracking are below 0.01\,m/s and 0.005\,rad/s, respectively. For path planning, the Hybrid A* algorithm generates a collision-free smooth path of 14.00\,m in a warehouse map with obstacles, and an infrared-sensor-based PID line-tracking controller achieves stable tracking with an RMS lateral error of 0.58\,cm.

    The results indicate that the proposed robot meets the design targets in structural strength, motion control accuracy, and path planning feasibility, providing a reference for the engineering development of similar lifting-type warehouse handling robots.
}

\vspace{1em}

\noindent\textbf{Key words:} intelligent warehouse mobile robot; differential drive; path planning; Hybrid A*; PID motion control

\setcounter{secnumdepth}{4}

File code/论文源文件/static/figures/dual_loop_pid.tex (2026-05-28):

% 双环PID控制原理框图（PPT用，紧凑版）
% 编译: xelatex dual_loop_pid.tex
\documentclass[tikz,border=4pt]{standalone}
\usepackage[scheme=plain]{ctex}

\usetikzlibrary{shapes,arrows,positioning,calc,backgrounds,fit}

\begin{document}
\begin{tikzpicture}[
    auto,
    node distance=1.0cm and 1.0cm,
    >=stealth',
    block/.style={
        rectangle, draw=black, thick,
        text width=1.8cm, minimum height=0.8cm,
        align=center, font=\tiny\sffamily,
        rounded corners=2pt,
    },
    sum/.style={
        circle, draw=black, thick,
        minimum size=5mm, inner sep=0pt,
    },
    branch/.style={
        circle, fill=black,
        minimum size=1.2mm, inner sep=0pt,
    },
    dashbox/.style={
        draw=blue!50, dashed, thick,
        rounded corners=4pt, inner sep=5pt,
    },
    line/.style={draw=black, thick, ->},
    fline/.style={draw=black!55, thick, ->},
]

% ==== 输入 ====
\node [font=\tiny\sffamily] at (-1.6,0) {$r(t)$};
\node [sum, right=0.8cm] (s1) {};
\node at (s1) {\tiny $-$};
\draw [line] (-1.1,0) -- (s1);

% ==== 外环PID ====
\node [block, right=1.2cm of s1] (PID1) {外环PID};
\draw [line] (s1) -- (PID1);

% ==== 内环求和 ====
\node [sum, right=1.2cm of PID1] (s2) {};
\node at (s2) {\tiny $-$};
\draw [line] (PID1) -- (s2);

% ==== 内环PID ====
\node [block, right=1.2cm of s2] (PID2) {内环PID};
\draw [line] (s2) -- (PID2);

% ==== 被控对象 ====
\node [block, right=1.2cm of PID2, text width=2.0cm] (G2) {$G_2(s)$};
\node [block, right=1.0cm of G2, text width=2.0cm] (G1) {$G_1(s)$};
\draw [line] (PID2) -- (G2);
\draw [line] (G2) -- (G1);

% ==== 输出 ====
\draw [line] (G1.east) -- ++(0.8,0) node [right, font=\tiny\sffamily] {$y(t)$};
\coordinate (out) at ($(G1.east)+(0.4,0)$);
\node [branch] at (out) {};

% ==== 内环反馈 ====
\coordinate (fb2) at ($(G2.east)!0.5!(G1.west)$);
\draw [fline] (fb2) |- ++(0,-1.0) -| (s2.south);
\node at (s2.south) {\tiny $-$};

% ==== 外环反馈 ====
\draw [fline] (out) |- ++(0,-1.5) -| (s1.south);
\node at (s1.south) {\tiny $-$};

% ==== 虚线框 ====
\begin{scope}[on background layer]
    \node [dashbox, fit=(PID1),
           label={[blue!50]above:{\tiny\bfseries 外环}}] {};
    \node [dashbox, fit=(PID2)(G2),
           label={[blue!50]above:{\tiny\bfseries 内环}}] {};
\end{scope}

\end{tikzpicture}
\end{document}

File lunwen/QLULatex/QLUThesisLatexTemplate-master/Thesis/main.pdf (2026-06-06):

# 本科毕业论文（设计）

## 智能仓储自主移动机器人结构设计与控制

学 部 （学 院） | 机械工程学院
专 业 班 级 | 机器人（SI）22-2
学 生 姓 名 | 王子煜
学 | 号 | 202201230042
导 师 姓 名 | 刘鹏博

2026 年 03 月 10 日

# 本 科 毕 业 论 文 （设 计）

## 智能仓储自主移动机器人结构设计与控制

学 部 （学 院） | 机械工程学院
专 业 班 级 | 机器人（SI）22-2
学 生 姓 名 | 王子煜
学 | 号 | 202201230042
导 师 姓 名 | 刘鹏博

2026 年 03 月 10 日

## 齐鲁工业大学本科毕业论文（设计）

## 原创性声明

本人郑重声明：所呈交的毕业论文（设计），是本人在指导教师的指导下独立研究、

撰写的成果。论文（设计）中引用他人的文献、数据、图件、资料，均已在论文（设计）

中加以说明，除此之外，本论文（设计）不含任何其他个人或集体已经发表或撰写的成

果作品。对本文研究做出重要贡献的个人和集体，均已在文中作了明确说明并表示了谢

意。本声明的法律结果由本人承担。

毕业论文（设计）作者签名：

年 | 月 | 日

## 齐鲁工业大学本科毕业论文（设计）

## 使用授权说明

本毕业论文（设计）作者完全了解学校有关保留、使用毕业论文（设计）的规定，

即：学校有权保留、送交论文（设计）的复印件，允许论文（设计）被查阅和借阅，学

校可以公布论文（设计）的全部或部分内容，可以采用影印、扫描等复制手段保存本论

文（设计）。

指导教师签名： | | | 毕业论文（设计）作者签名：
年 | 月 | 日 | 年 | 月 | 日

齐鲁工业大学 2026 届本科毕业论文（设计）
目 | 录
摘 | 要 ··························································································· | I

ABSTRACT ······················································································· II 第 1 章 引言 ····················································································· 1

1.1 研究背景和意义 ······································································ 1

### 1.2 自主移动机器人在智能仓储场景中的国内外研究现状 ·············· 2

1.2.1 国外研究现状 ································································· 2

1.2.2 国内研究现状 ································································· 3

1.3 国内外智能仓储移动机器人路径规划算法研究现状 ·················· 3

1.4 研究方法与手段 ······································································ 4

1.5 小结 ························································································ 5

第 2 章 智能仓储移动机器人总体设计方案 ···································· 6

2.1 设计需求分析 ·········································································· 6

2.2 驱动方案选择 ·········································································· 6

2.2.1 单轮驱动 ········································································ 6

2.2.2 差速驱动 ········································································ 7

2.2.3 全方位驱动 ····································································· 7

2.2.4 方案选择 ········································································ 8

2.3 升降机构方案选择 ··································································· 8

2.4 控制系统方案选择 ··································································· 9

2.5 驱动电机方案选择 ··································································· 10

2.6 运动控制算法选择 ··································································· 10

2.7 路径规划算法选择 ··································································· 11

2.8 总体方案概述 ·········································································· 13

2.9 小结 ························································································ 13

第 3 章 智能仓储移动机器人机械结构设计 ···································· 14

3.1 剪叉式垂直升降机构设计 ························································ 14

3.1.1 机构选型依据 ································································· 14

3.1.2 机构结构组成 ································································· 15

3.1.3 材料选择 ········································································ 16

3.2 升降机构工作原理与运动学分析 ·············································· 16

3.2.1 运动学建模 ····································································· 16

3.2.2 工作参数 ········································································ 18

3.3 升降机构受力分析与载重计算 ················································· 18

3.3.1 额定载重设定 ································································· 18

3.3.2 剪叉臂受力分析 ······························································ 18

3.3.3 各工作角度下的受力变化 ················································ 19

3.4 关键部件强度校核 ··································································· 20

3.4.1 剪叉臂杆截面特性 ·························································· 20

3.4.2 臂杆压弯组合强度校核 ··················································· 20

3.4.3 臂杆屈曲稳定性校核 ······················································· 21

3.4.4 铰接销轴强度校核 ·························································· 22

3.4.5 承载平台强度校核 ·························································· 23

3.4.6 有限元数值验证 ······························································ 23

3.5 小结 ························································································ 25

第 4 章 智能仓储移动机器人电气系统设计 ···································· 27

4.1 电气系统总体架构 ··································································· 27

4.1.1 智能仓储移动机器人主控制器选择 ·································· 27

4.2 电机，传感器等部件选型 ························································ 28

4.2.1 电机选型 ········································································ 28

4.2.2 减速器选型 ····································································· 31

4.2.3 传感器选型 ····································································· 33

4.3 控制电路设计 ·········································································· 35

4.3.1 STM32F103C8T6 最小系统 ·············································· 35

4.3.2 传感器接口电路设计 ······················································· 36

4.4 小结 ························································································ 37

第 5 章 智能仓储移动机器人运动学建模与仿真 ···························· 38

5.1 典型运动轨迹仿真与分析 ························································ 39

5.1.1 直线运动 ········································································ 39

5.1.2 圆弧运动 ········································································ 40

5.1.3 S 形运动 ········································································· 41

5.1.4 8 字形运动 ······································································ 41

5.2 路径规划与循迹仿真 ······························································· 44

5.2.1 Hybrid A* 路径规划算法 ·················································· 45

5.2.2 路径规划仿真结果 ·························································· 46

5.2.3 红外传感器循迹模型 ······················································· 46

5.2.4 循迹仿真结果与分析 ······················································· 48

5.3 小结 ························································································ 50

第 6 章 智能仓储移动机器人运动控制算法分析 ···························· 51

6.1 PID 控制算法原理 ··································································· 51

6.2 双轮差速 PID 控制器设计 ························································ 51

6.3 基本运动控制实现 ··································································· 53

6.4 控制效果仿真验证 ··································································· 53

6.4.1 阶跃响应 ········································································ 54

6.4.2 定点镇定 ········································································ 54

6.4.3 S 形轨迹跟踪 ·································································· 55

6.4.4 圆形轨迹跟踪 ································································· 56

6.5 小结 ························································································ 61

第 7 章 结论 ····················································································· 62

7.1 全文工作总结 ·········································································· 62

7.2 不足与改进方向 ······································································ 62

7.3 应用前景展望 ·········································································· 63

参考文献 ··························································································· 64

致 谢 ··························································································· 66

附录 A MATLAB 仿真程序代码 ······················································· 67

摘 要

针对中小型仓储场景中物料搬运自动化程度不足的问题，本文设计了一款集成剪叉

式举升功能的双轮差速驱动移动机器人。通过多方案对比，确定了" 交流伺服电机 + 行

星减速器" 的动力方案、ARM 单片机嵌入式控制系统，以及 Hybrid A* 全局路径规划与

双环 PID 运动控制相配合的导航控制策略。

升降机构运动学建模与强度校核表明，在 50 kg 额定载重下，臂杆最危险工况的压

弯组合应力仅为 5.56 MPa，承载平台 von Mises 等效应力为 14.1 MPa，均远低于 Q235 钢

156.7 MPa 的许用应力；增设侧向支撑后，臂杆屈曲安全系数由 2.54 升至 10.1，结构安

全裕度充足。

MATLAB 控制仿真覆盖了阶跃响应、定点镇定、直线跟踪和圆形轨迹跟踪四种典型

工况。定点镇定终点位置误差收敛至厘米级，航向偏差小于 1

◦；连续轨迹跟踪的线速度

与角速度 RMSE 分别低于 0.01 m/s 和 0.005 rad/s。路径规划方面，Hybrid A* 算法在含障

碍物的仓储地图上生成了长 11.04 m 的无碰撞平滑路径，红外循迹 PID 控制器以 1.5 cm

的 RMS 横向误差实现了对该路径的稳定跟踪。

研究结果表明，本文所设计的机器人在结构强度、运动控制精度与路径规划可行性

方面均达到预期指标，可为同类举升式仓储搬运机器人的工程研制提供参考。

关键词：智能仓储移动机器人；差速驱动；路径规划；Hybrid A*；PID 运动控制

I

### ABSTRACT

Aiming at the insufficient automation of material handling in small-to-medium ware-

house environments, this thesis presents a dual-wheel differential-drive mobile robot with

an integrated scissor-type lifting mechanism. Through comparative analysis of multiple de-

sign options, an AC servo motor with planetary reducer drive scheme, an ARM Cortex-M

microcontroller-based embedded control system, and a navigation strategy combining Hybrid

A* global path planning with dual-loop PID motion control are established.

Kinematic modeling and strength verification of the lifting mechanism demonstrate that,

under the rated payload of 50 kg, the combined compressive-bending stress of the scissor arm

in the worst-case condition is merely 5.56 MPa, and the von Mises equivalent stress of the loading platform is 14.1 MPa —both far below the 156.7 MPa allowable stress of Q235 steel.

With lateral bracing added, the buckling safety factor of the arm increases from 2.54 to 10.1,

providing an ample safety margin.

MATLAB control simulations cover four typical scenarios: step response, point stabi-

lization, straight-line tracking, and circular trajectory tracking. The terminal positioning error in point stabilization converges to the centimeter level with heading deviation under 1◦
; the

RMSE of linear and angular velocities in continuous trajectory tracking are below 0.01 m/s and

0.005 rad/s, respectively. For path planning, the Hybrid A* algorithm generates a collision-free

smooth path of 11.04 m in a warehouse map with obstacles, and an infrared-sensor-based PID

line-tracking controller achieves stable tracking with an RMS lateral error of 1.5 cm.

The results indicate that the proposed robot meets the design targets in structural strength,

motion control accuracy, and path planning feasibility, providing a reference for the engineering

development of similar lifting-type warehouse handling robots.

Key words: intelligent warehouse mobile robot; differential drive; path planning; Hybrid A*;

PID motion control

II

## 第 1 章 引言

### 1.1 研究背景和意义

根据商务部发布的《中国新电商发展报告（2025）》[1]，2024 年我国网络零售额达

到 15.5 万亿元，同比增长 7.2%，对社会消费品零售总额贡献约 1.7 个百分点，我国已连

续 12 年保持全球最大网络零售市场的地位，相关数据见图1-1。电商规模的持续扩大使

仓储与物流环节逐步演变为整体效率提升的主要瓶颈。依靠人工完成的仓储作业在效率

和响应速度上已无法匹配不断攀升的订单量，这一现实促使学术界和产业界将目光投向

智能仓储中的自主移动机器人。

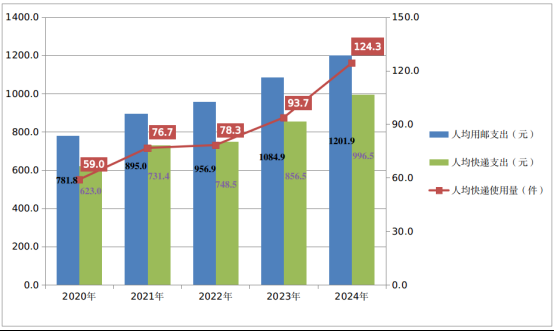
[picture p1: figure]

图 1-1 2020-2024 年人均用邮支出、快递支出和快递使用量情况

在智能仓储领域，自主移动机器人根据导航方式和功能定位可划分为若干类型。自

动导引车（AGV）依靠磁条、二维码等预设标识导航，适用于路径固定的场景；自主移

动机器人（AMR）引入激光雷达、视觉传感器和 SLAM 技术，具备自主感知与动态决

策能力，适合复杂多变的仓储环境。各类机器人的核心目标高度一致——在仓储场景中

实现高效、安全、自主的物料搬运。

自动导引车（AGV）集自主导航、路径规划和货物搬运于一体，可在结构化仓储场

景中独立完成物流作业，图1-2展示了典型 AGV 的工作状态。市场数据表明，2019 年至

2024 年中国 AGV 行业规模从 48.27 亿元攀升至 95.49 亿元；AMR 市场同样增长迅猛，

2023 年规模已突破 60 亿元，年增长率超过 30%，反映出行业从" 固定路径导引" 向" 自

主感知决策" 升级的清晰趋势。

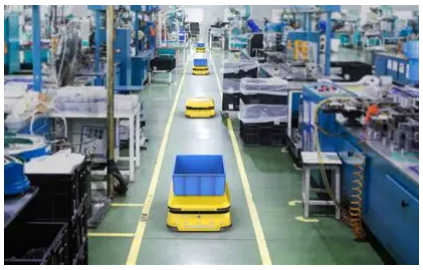
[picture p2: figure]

图 1-2 AGV 工作示意图

然而，随着电商物流向更多品类、更高时效的方向发展，仓储场景对自主移动机器

人提出了更高要求：作业环境日趋动态化，柔性订单结构使搬运路径不再固定，机器人

需在人机混行环境中稳定运行；系统需从固定路径导引升级为自主感知与实时决策[2]；

在环境感知、路径规划和任务调度等方面，需兼顾全局最优性与局部实时性。

在上述挑战驱动下，自主移动机器人的研究已延伸至环境感知与运动控制深度融

合、多机协同调度等深层次问题。但目前针对中小型仓储场景中兼具举升功能与自主导

航能力的紧凑型机器人的系统性工程研究仍不充分。本文以一款举升式自主搬运机器人

为研究对象，围绕总体方案设计、机械与电气系统、运动学建模与运动控制等关键环节

展开研究，旨在为该类机器人的设计与开发提供理论依据和技术参考。

### 1.2 自主移动机器人在智能仓储场景中的国内外研究现状

### 1.2.1 国外研究现状

国外在自主移动机器人领域的研发和商业化起步较早。亚马逊 2012 年收购 Kiva

Systems 后批量部署 Kiva 机器人，以" 货架到人" 模式将拣选效率提高 2 至 3 倍[2]，其

通过中央调度协调多机器人协同的理念深刻影响了行业走向。近年来 AMR 成为新趋势，

Fetch Robotics、Locus Robotics 等公司推出的 AMR 利用激光雷达和 SLAM 实现自主定

位，无需改造仓库地面即可部署[3]。欧洲方面，Magazino 的 TORU 实现了从搬运货架到

视觉抓取单品的技术跨越，KUKA 和 ABB 等将机械臂与移动底盘结合推出复合型移动

操作机器人[4]。波士顿动力的 Atlas 和 Spot 则在复杂地形适应方面展现出高水平。

在算法维度，Hybrid A* 因能生成满足运动约束的路径而被广泛采纳[5]，MAPF 为

多机协同提供了理论支撑。近年研究焦点转向深度强化学习（DQN、PPO）的落地应用，

以及数字孪生仿真、云-边-端协同调度等方向。自主移动机器人的应用也从仓储拓展到

智能城市、医疗和农业等领域[6]。

### 1.2.2 国内研究现状

国内对自主移动机器人的研究可追溯至 20 世纪 70 年代末，早期以引进仿制为主。

进入 21 世纪后，制造业升级与电商增长使仓储机器人成为关注焦点，2012 年亚马逊收

购 Kiva 更推动了国内企业的布局。

在产业应用层面，京东物流自 2014 年起建设亚洲一号智能仓群，自主研发了" 地

狼"AGV 和" 天狼" 穿梭系统，并与极智嘉（Geek+）合作引入 AMR 方案[4]。菜鸟网络

在无锡、惠阳等地部署了数百台 AGV 与 AMR，其" 小蛮驴" 配送机器人将应用从仓储

延伸至末端配送。海康威视、旷视科技、快仓等企业在仓储机器人领域形成成熟产品线，

国产化产业链逐步成形[3]。

技术层面，导航技术从磁条/二维码引导迭代至激光 SLAM 和视觉 SLAM 方案[7]；

多机协同方面提出了多种分布式和集中式调度策略；算法方面围绕改进 A*、遗传算法、

蚁群算法等积累了理论成果。总体而言，国内在核心算法成熟度和大规模部署经验上与

国际先进水平仍有差距，但差距正在收窄，应用前景广阔。

### 1.3 国内外智能仓储移动机器人路径规划算法研究现状

在国外研究方面，M Rybczak 等人梳理了移动机器人控制中机器学习算法面临的计

算资源、实时决策、环境适应性和安全可靠性等挑战[8]。MFR Lee 等人将深度 Q 网络

（DQN）和双深度 Q 网络（DDQN）引入移动机器人导航与避撞学习[9]。Y Dai 等人剖析

了传统鲸鱼优化算法及其改进方法在移动机器人路径规划中的不足[10]。S Das 等人提出

了自适应随机梯度下降线性回归（ASGDLR）算法，用于识别自主移动机器人左右转向

运动特征[11]。B Tao 等人提出了具有随机扰动策略的双种群粒子群优化算法，以改善传

统粒子群优化在约束问题中的局限性[12]。T Guo 等人提出了一种基于改进 A* 和动态窗

口法（DWA）融合的 AGV 路径规划算法，旨在解决传统 A* 搜索效率低、不考虑 AGV

尺寸和转弯次数过多，以及 DWA 易陷入局部最优的问题[13]。K Fransen 等人提出了一种

改进的 A* 算法启发式方法，可用于在具有转向成本的几何图中找到最低成本路径[14]。

T Heinemann 等人提出了一种路径规划概念及评估方法，用于改进向量场直方图（vector

field histogram）和动态窗口（dynamic window）算法，以实现平滑轨迹生成[15]。

在国内研究方面，学者们围绕仓储机器人路径规划与轨迹跟踪进行了大量探索。黄

晓宇等人设计了一种模型预测控制（MPC）与微分先行比例-积分-微分（PID）协同的双

闭环控制策略，用于麦克纳姆轮全向移动平台的轨迹跟踪控制[16]。曹梦龙等人梳理了机

器人路径规划的基本步骤，并概述了群体智能优化算法在路径规划中的应用[17]。白宇鑫

等人提出了改进的哈里斯鹰优化算法以解决机器人路径规划问题，并剖析了 HHO 算法

在收敛性和局部最优方面的局限性[18]。赖荣燊等人探讨了传统 A* 算法与动态窗口法的

优缺点及其改进方向[19]。张瑞等人提出了 RRT* 与 DWA 融合的路径规划方法，旨在提

升复杂动态环境下移动机器人路径规划的安全性和最优性[20]。肖金壮等人设计了一种

面向室内自动导引车（AGV）路径规划的改进蚁群算法，旨在解决传统算法在大规模和

复杂环境中全局搜索效率差、收敛速度慢以及路径转弯次数过多和不够平滑的问题[21]。

张中伟等人提出了一种基于动态优先级策略的多 AGV 无冲突路径规划方法，用于柔性

制造车间的高效平稳生产。该方法通过动态调整 AGV 的优先级，优化路径规划过程，减

少冲突和等待时间，提高整体生产效率[22]。张天瑞等人探讨了针对基本蚁群算法在机器

人路径规划过程中存在的路径转弯角度大、易陷入局部极小值和收敛速度慢等问题所进

行的改进策略[23]。李玉清等人设计了一种针对自动导引车（AGV）路径规划的改进动态

窗口法（DWA）算法，该算法克服了原始 DWA 存在的振荡现象，并融合了人工势场法

（APF）以提升路径规划的安全性和效率[24]。

综合来看，国内外在智能仓储移动机器人路径规划算法方面已经形成了较为系统的

研究基础，研究脉络主要经历了从传统启发式搜索到融合运动学约束的规划方法，再到

结合机器学习与多机协同的智能化发展过程，后续研究重点将继续聚焦高效规划、动态

避障与复杂场景下的协同决策。

### 1.4 研究方法与手段

本文研究对象为一款具备举升功能的自主搬运机器人，集载货、升降与运输于一体。

底盘采用差速驱动方式，由两侧独立驱动轮和四个万向轮组成，通过左右轮速度差实现

行驶和转向；升降机构选用剪叉式结构；控制策略采用 PID 控制器。总体方案已在第二

章详细论证。

本文的主要工作包括：

1. 总体方案设计：确定差速底盘、驱动电机、升降机构、控制器和路径规划方案；
2. 机械结构设计：完成总体结构布局设计，并对剪叉式升降机构进行结构设计、运动学

建模、受力分析及关键部件强度校核；

3. 电气系统设计：完成主控制器、电机、传感器选型及电路原理图设计；

4. 运动学建模、路径规划与仿真：建立差速运动学模型，利用 MATLAB 进行典型轨迹

仿真，并基于 Hybrid A* 算法完成路径规划与红外循迹仿真验证；

5. 运动控制研究：设计双环 PID 控制器并通过仿真验证控制性能；
6. 结论与展望：总结成果，指出不足并提出改进方向。

1.5 小结

本章阐述了研究的背景和意义，分析了国内外智能仓储移动机器人和路径规划算法

的研究现状，明确了本文的研究内容、研究方法和技术路线。在充分调研的基础上，为

举升式自主搬运机器人的设计与控制奠定了理论基础。

## 第 2 章 智能仓储移动机器人总体设计方案

### 2.1 设计需求分析

智能仓储环境对搬运设备的运行效率、空间适应性和自动化程度提出了明确要求。

在货架密集、通道狭窄的仓储场景中，搬运设备需具备自主行驶、货物装卸和障碍规避

等基本能力，同时应兼顾部署成本、维护便利性和运行可靠性。本章从系统总体设计的

角度出发，围绕驱动方式、驱动电机、升降机构、控制系统、运动控制算法和路径规划

算法六个方面展开方案论证，为后续各章的设计与仿真提供整体框架。

本设计所面向的典型应用场景为中小型仓储环境中的物料搬运任务。此类场景具有

以下特征：货架排列较为规整，通道宽度有限；搬运对象以轻型物料为主，单次搬运重

量一般不超过 50 kg；作业区域为平整室内地面，无较大坡度或颠簸；运行路径可在作

业前预先规划，环境变动频率较低。基于上述场景特点，设计需在满足功能需求的前提

下，尽可能降低系统复杂度和硬件成本，同时为后续的功能扩展预留接口。

综合以上分析，本文将设计目标归纳如下：（1）移动机器人能够自主沿规划路径行

驶，完成从取货点到目标货架之间的物料搬运；（2）具备载物台升降功能，升降行程不

小于 0.4 m，以适应不同货架高度的搬运需求；（3）具备基本的障碍物检测与避障能力，

保障运行安全；（4）外形尺寸紧凑，能够在狭窄通道中灵活通行；（5）系统结构简洁、

控制可靠、成本可控，适合实际部署与维护。

### 2.2 驱动方案选择

驱动方式是移动机器人底盘设计的核心环节，直接决定车辆的运动性能、控制复杂

度以及适用的工作场景。驱动方式的选择需综合考虑载荷能力、转向灵活性、控制精度、

结构可靠性和制造成本等多方面因素。目前，移动机器人常用的驱动形式可归纳为三类：

单轮驱动、差速驱动和全方位驱动。

2.2.1 单轮驱动

单轮驱动的特征在于由一个舵轮同时承担驱动与转向两项功能，从动轮对称布置在

车体轴线两侧，如图2-1所示。该方案结构简洁，零部件数量少，可靠性较高，维护成本

低。其局限性在于转弯半径偏大，灵活性不足，在空间狭窄或需要频繁转向的仓储通道

中表现不够理想。此外，舵轮机构在转向过程中驱动轮与地面之间存在侧向滑移，长期

运行会加速轮胎磨损。

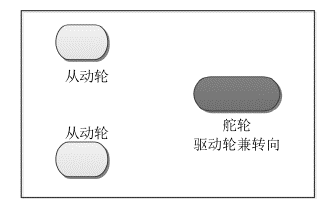
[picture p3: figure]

图 2-1 单轮驱动示意图

2.2.2 差速驱动

差速驱动由两个独立驱动的驱动轮和四个从动万向轮组成，左右驱动轮对称分布在

车体轴线两侧，如图2-2所示。其转向原理不依赖转向机构，而是通过调节左右驱动轮的

速度差来实现：当两侧轮速相等时，车辆直线行驶；当两侧轮速不等时，车辆向低速侧

偏转。这种驱动方式能够实现前进、后退和原地转向，转弯半径小、灵活性出色，特别

适合仓储通道中的频繁转向和狭窄空间作业。差速驱动的不足在于对地面平整度有一定

要求——在凹凸不平的地面上，从动万向轮可能出现悬空现象，影响行驶稳定性；此外，

差速转向过程中驱动轮与地面之间存在一定的滑动摩擦，长期运行会加速轮胎磨损。

图 2-2 差速驱动示意图

2.2.3 全方位驱动

全方位驱动追求平面内的全向运动能力，常见方案包括两种：一是前后各设置一个

舵轮并搭配从动万向轮，通过控制舵轮的角度和转速实现全向移动，如图2-3所示；二是

采用四个麦克纳姆轮，通过独立控制各轮转速和方向，借助速度矢量合成实现平移、斜

行和原地旋转。

图 2-3 全方位驱动示意图

全方位驱动的突出优势在于可在不改变车体姿态的前提下向任意方向移动，空间利

用率极高。然而其实现代价显著：麦克纳姆轮结构复杂，制造精度要求高，辊子磨损较

快；舵轮方案需要高精度伺服控制，对电机性能和控制系统实时性要求较高。两类方案

的硬件成本、控制难度和后期维护费用均明显高于前两种驱动方式。

2.2.4 方案选择

三者的综合对比见表2-1。

表 2-1 驱动方案综合对比
对比维度 | 单轮驱动 | 差速驱动 | 全方位驱动
结构复杂度 | 低 | 较低 | 高
转弯半径 | 较大 | 小（可原地转向） 极小（全向移动）
控制难度 | 低 | 中等 | 高
制造成本 | 低 | 较低 | 高
地面适应性 | 较好 | 要求地面平整 | 较好
灵活性 | 一般 | 好 | 极好

结合本文设计目标进行权衡：仓储通道空间有限，要求车辆具备较小的转弯半径和

良好的转向灵活性，单轮驱动在此方面存在明显不足；全方位驱动虽灵活性极佳，但其

结构复杂、成本高昂，对于路径相对固定的仓储搬运场景而言，全向移动能力属于功能

冗余，性价比不高。差速驱动在结构复杂度、转弯灵活性和制造成本之间取得了较好的

平衡：其转弯半径小，能够在狭窄通道中完成转向和姿态调整；结构以驱动轮和万向轮

为主，零部件标准化程度高，制造和维护成本可控；控制策略基于左右轮速差，算法成

熟且易于实现。因此，本文最终选定差速驱动作为举升式移动机器人的底盘驱动方案。

### 2.3 升降机构方案选择

本文设计的移动机器人需具备货物装卸能力，即在货架前完成载物台的升降操作，

以适应不同高度的货架层。升降机构作为衔接底盘与载物平台的关键功能模块，其选型

直接影响整机的承载能力、升降平稳性和空间利用率。

仓储搬运设备中常见的升降机构主要包括三种类型：剪叉式、桅柱式和套筒式。剪

叉式升降机构由多组交叉臂杆组成，通过液压缸或电动推杆驱动臂杆的张开与收拢来实

现平台的升降运动。其突出优点是结构紧凑、传动平稳，在收拢状态下占用高度小，展

开后能获得较大的升降行程，承载能力与自身重量的比值较高。桅柱式升降机构由竖直

导轨和滑动平台构成，通过链条或丝杠驱动平台沿导轨上下运动，承载刚性好、定位精

度高，但整体高度较大，对仓储天花板净空有一定要求。套筒式升降机构采用多级套叠

结构，类似液压缸的逐级伸出原理，收缩后体积小，适合极低净空场合，但行程受限，且

多级导向精度随着级数增加而降低。

三种方案的定性对比见表2-2。

表 2-2 升降机构方案对比
对比维度 | 剪叉式 | 桅柱式 | 套筒式
结构紧凑性 | 好（收缩高度小） 一般 | 好
承载能力 | 中等偏高 | 高 | 较低
升降平稳性 | 好 | 好 | 一般（多级间隙累 加）
行程/收缩比 | 大 | 受导轨长度限制 | 中等
制造成本 | 中等 | 较高 | 中等

本文设计的小车载重不超过 50 kg，属于轻型载荷范畴，升降行程要求为 0.4 m。在

这一工况下，桅柱式方案的高刚度优势无法充分发挥，而其较大的纵向尺寸反而会增大

整车高度，降低在低层货架区域的通过性；套筒式方案在多级伸缩过程中存在导向间隙

累积问题，升降平稳性不及前两者。剪叉式升降机构以紧凑的结构实现了较大的行程/收

缩比，传动平稳、无明显的纵向尺寸冗余，且制造工艺成熟、成本可控，与本文所设计

小型搬运车的轻载、紧凑、平稳三项核心需求高度吻合。因此，本文选用剪叉式结构作

为载物台的升降方案。

### 2.4 控制系统方案选择

控制系统是移动机器人的决策与执行中枢，负责传感器数据采集、控制算法运算、

驱动信号输出以及各子系统的协调管理。控制系统方案的选择需在计算能力、实时性、

功耗、接口资源、开发难度和硬件成本之间做出合理权衡。

工业控制领域常用的控制器方案主要有四类。PLC 以高可靠性和强抗干扰能力著

称，但体积大、成本高，算法灵活性有限。工控机计算能力强、操作系统完善，但功耗

高、启动慢，适合作为固定调度主机而非移动平台嵌入式控制器。DSP 专为高速信号

处理设计，但在通用外设接口和扩展能力方面不及单片机，且成本与功耗较高。单片机

（MCU）以 ARM Cortex-M 系列为代表，将处理器内核、存储器、定时器和通信接口集

成于单一芯片，体积小、功耗低、实时性强，丰富的外设接口可直接连接传感器和编码

器等外围器件，开发工具链成熟、成本低廉。

本文所设计搬运车的控制任务主要包括传感器数据采集、PID 运动控制律执行、轮

速解算和 PWM 驱动信号生成，计算负载适中而实时性要求较高，属于典型的嵌入式控

制场景。因此，本文选择以 ARM Cortex-M 系列单片机为核心构建主控制器，兼顾性能、

功耗与成本。

### 2.5 驱动电机方案选择

驱动电机是移动机器人动力系统的核心执行部件，其类型直接决定调速性能、控制

精度和运行可靠性。常用的驱动电机主要有四类。直流有刷电机结构简单、成本低，但

电刷存在机械磨损，换向火花产生电磁干扰，不利于精密控制。直流无刷电机效率高、

寿命长，但低转速时齿槽效应导致转矩脉动明显，难以满足低速平稳性要求。步进电机

可通过脉冲信号实现开环位置控制，但高速转矩下降显著，存在丢步和共振风险，不适

合长距离连续运行。交流伺服电机采用闭环控制，编码器实时反馈转速与位置，调速范

围宽、低速平稳性好、过载能力强，能够精确跟踪轮速指令，为轨迹跟踪和航位推算提

供可靠的执行保证。

本设计采用差速驱动方式，对轮速控制精度和低速平稳性有较高要求。综合以上对

比，本文选择交流伺服电机作为驱动电机，具体型号的功率和转矩参数将在电气系统设

计章节中进行定量计算与校核。

### 2.6 运动控制算法选择

移动机器人的运动控制本质上是一个闭环跟踪问题：控制器根据期望位姿或期望速

度与实际状态之间的偏差，实时计算控制量并驱动电机，使机器人沿预定轨迹稳定运行。

控制算法的选择直接关系到系统的跟踪精度、响应速度和抗干扰能力。

PID（比例—积分—微分）控制是工业控制领域应用最为广泛、技术最为成熟的经

典算法，至今已有近百年的工程应用历史。其基本思想是将期望值与实际值之间的偏差

按比例、积分和微分三种运算进行加权组合，生成控制输出量。比例环节对当前偏差进

行即时响应，提供控制作用的主体部分；积分环节对历史偏差进行累积，用于消除长时

间运行中可能出现的稳态误差；微分环节对偏差的变化趋势进行预估，起到抑制超调和

减小振荡的作用。三个环节的作用相互独立、物理意义明确，工程人员可通过调节三个

增益系数来匹配不同被控对象的动态特性。

在移动机器人运动控制领域，除经典 PID 之外，常用的控制方法还包括模糊控制和

模型预测控制（MPC）。模糊控制将专家经验转化为模糊规则库，通过模糊推理实现非

线性映射，对系统精确数学模型的依赖程度较低，适合难以精确建模的复杂系统，但其

规则库的设计高度依赖经验，调试过程主观性强，控制精度不易保证。MPC 基于系统模

型对未来一段时间内的状态进行预测，通过在线求解有限时域优化问题获得最优控制序

列，能够显式处理状态约束和输入约束，理论性能优异，但其计算量较大，对控制器运

算能力要求较高，且需要相对准确的系统动力学模型，在低成本嵌入式平台上的实时实

现具有一定挑战。

表2-3从实现难度、实时性、模型依赖和适用场景等维度对三种控制方法进行了对

比。

表 2-3 运动控制算法对比
对比维度 | PID 控制 | 模糊控制 | 模型预测控制
实现难度 | 低 | 中等 | 高
计算量 | 小 | 中等 | 大
模型依赖 | 低 | 低 | 高（需系统模型）
参数整定 | 成熟（Z-N 法等） 依赖经验 | 需优化求解
稳态精度 | 好（含积分项） | 一般 | 好
约束处理 | 无显式处理 | 无显式处理 | 可显式处理

结合本文设计目标进行考量：本系统采用双轮差速驱动，被控对象为左右轮转速和

车体姿态，运动模型相对简单、非线性程度不高，PID 控制器完全具备处理此类控制问

题的能力；系统主控制器为单片机，计算资源有限，PID 的运算量极小（仅包含数次乘加

运算），能够在毫秒级的控制周期内完成，与嵌入式平台的实时性要求高度匹配；PID 参

数整定方法成熟，无论是基于 Ziegler-Nichols 经验公式的工程整定，还是借助 MATLAB

的仿真辅助整定，均有成熟的实施路径。相比之下，模糊控制在简单线性系统中的精度

优势并不明显，而 MPC 的计算开销在单片机平台上难以满足 5 ms 控制周期的实时性要

求。因此，本文选择 PID 控制作为运动控制的基础算法，并通过双环级联（外环位姿环

与内环轮速环）的结构来兼顾轨迹跟踪与姿态调节的精度需求。

### 2.7 路径规划算法选择

路径规划是移动机器人导航系统的核心功能模块，其任务是在包含障碍物的环境中

寻找一条从起点到终点的安全可行路径。路径规划算法的选择需同时考虑搜索效率、路

径质量、运动学可行性以及与底层控制器的衔接便利性。

在仓储移动机器人领域，常用的全局路径规划算法包括 Dijkstra 算法、标准 A* 算

法和 Hybrid A* 算法等。Dijkstra 算法采用广度优先的搜索策略，能够保证找到全局最短

路径，但其搜索过程不具备方向引导性，节点扩展量大，在较大规模地图上运行效率较

低。标准 A* 算法在 Dijkstra 的基础上引入了启发式函数，使搜索过程有方向性地朝向目

标点推进，显著提高了搜索效率，是目前应用最广泛的栅格路径规划算法。然而，标准

A* 算法在离散栅格上仅允许 8 邻域（或 4 邻域）移动，生成的路径由栅格边或栅格对

角线连接而成，存在锯齿状折线，不符合差速驱动移动机器人的运动学约束——实际机

器人无法执行突变方向的路径。通常需要在 A* 规划之后增加路径平滑后处理步骤，但

这种后处理方式不能保证平滑后的路径仍然满足无碰撞要求。

Hybrid A* 算法是专门针对非完整约束移动机器人（如差速驱动车辆）设计的路径

规划方法。其在标准 A* 的栅格搜索框架之上做了两个关键改进：第一，节点状态从二

维位置 (x, y) 扩展为三维位姿 (x, y, θ)，将航向信息纳入搜索空间；第二，节点的后继扩

展不再局限于栅格邻域，而是采用符合差速运动学模型的连续曲率运动基元，每个基元

对应特定的转向曲率和行驶方向。这两项改进使 Hybrid A* 生成的路径天然满足机器人

的最小转弯半径约束，避免了标准 A* 规划结果中可能出现的不可执行急转弯，路径可

直接交付底层控制器跟踪执行，无需额外的后处理。此外，Hybrid A* 在代价函数中可

引入转向惩罚和倒车惩罚，引导算法优先选择平滑、前向的路径。

表2-4从搜索效率、路径运动学可行性和实现复杂度等维度对三种算法进行了定性

对比。

表 2-4 路径规划算法对比
对比维度 | Dijkstra | 标准 A* | Hybrid A*
搜索效率 | 低（无启发引 导） | 高（有启发引导） | 中等（状态维 数更高）
路径最优性 | 全局最优 | 启发式最优 | 运动学约束下 近似最优
运动学可行性 | 不支持（需后 处理） | 不支持（需后处 理） | 天然满足
转弯半径约束 | 不考虑 | 不考虑 | 显式考虑
实现复杂度 | 低 | 低 | 中等

结合本文的应用场景，仓储环境中的货架布局相对固定，地图可预先构建，路径规

划可在离线状态下完成，对算法的实时运行效率要求不如在线规划严苛。在此前提下，

路径质量（即路径的可执行性和平滑性）成为比搜索速度更优先的考量因素。Hybrid A*

虽然搜索效率略低于标准 A*，但其生成的路径满足差速底盘的运动学约束，无需后处

理即可直接由底层 PID 控制器执行，大幅降低了导航系统各层之间的衔接复杂度。此外，

当仓储货架布局发生变化时，Hybrid A* 可基于更新后的地图重新规划路径，无需人工

重新铺设地面引导标识，提升了系统的灵活性和可维护性。因此，本文选择 Hybrid A*

作为全局路径规划算法。

### 2.8 总体方案概述

综合以上各节的分析与论证，本文所设计的智能仓储移动机器人总体方案如下：

（1）驱动方案：双轮差速驱动底盘，转弯半径小、灵活性好；

（2）驱动电机：交流伺服电机，闭环控制，低速平稳、调速范围宽；

（3）升降机构：剪叉式升降结构，传动平稳、结构紧凑，行程满足 0.4 m 指标；

（4）控制系统：ARM Cortex-M 系列单片机，兼顾性能、实时性与成本；

（5）运动控制：双环 PID 级联控制，外环位姿环与内环轮速环，适合嵌入式平台；

（6）路径规划：Hybrid A* 算法，路径天然满足差速运动学约束，无需后处理。

上述方案构成了层次清晰的总体设计框架：顶层由 Hybrid A* 负责路径决策，中间层由

PID 控制器负责运动跟踪，底层由伺服电机驱动的差速底盘和剪叉式升降机构负责物理

执行，单片机作为控制中枢贯穿各层。各方案的选择均以场景需求为出发点，在功能、技

术成熟度、实现可行性和成本之间进行了综合权衡，为后续各章的详细设计提供指导。

2.9 小结

本章从智能仓储的实际需求出发，完成了移动机器人总体方案的设计与论证。在驱

动方式、驱动电机、升降机构、控制系统、运动控制算法和路径规划算法六个方面，通

过多方案对比分析，分别选定了差速驱动、交流伺服电机、剪叉式升降机构、单片机控

制器、双环 PID 控制和 Hybrid A* 算法。各方案的选择均建立在场景需求和方法对比的

基础上，兼顾了功能完整性、技术可行性和工程经济性，为后续各章的设计与仿真提供

了明确的指导框架。

## 第 3 章 智能仓储移动机器人机械结构设计

本设计的智能仓储移动小车采用差速驱动方式，由交流伺服电机驱动两个独立的驱

动轮。小车搭载剪叉式升降机构，可实现货物的垂直搬运。整体结构兼具运动灵活性和

承载能力，能够满足复杂仓储环境下的物流配送需求。其总体结构如图3-1所示，主要由

车身、驱动轮、升降机构和控制系统四大部分组成。

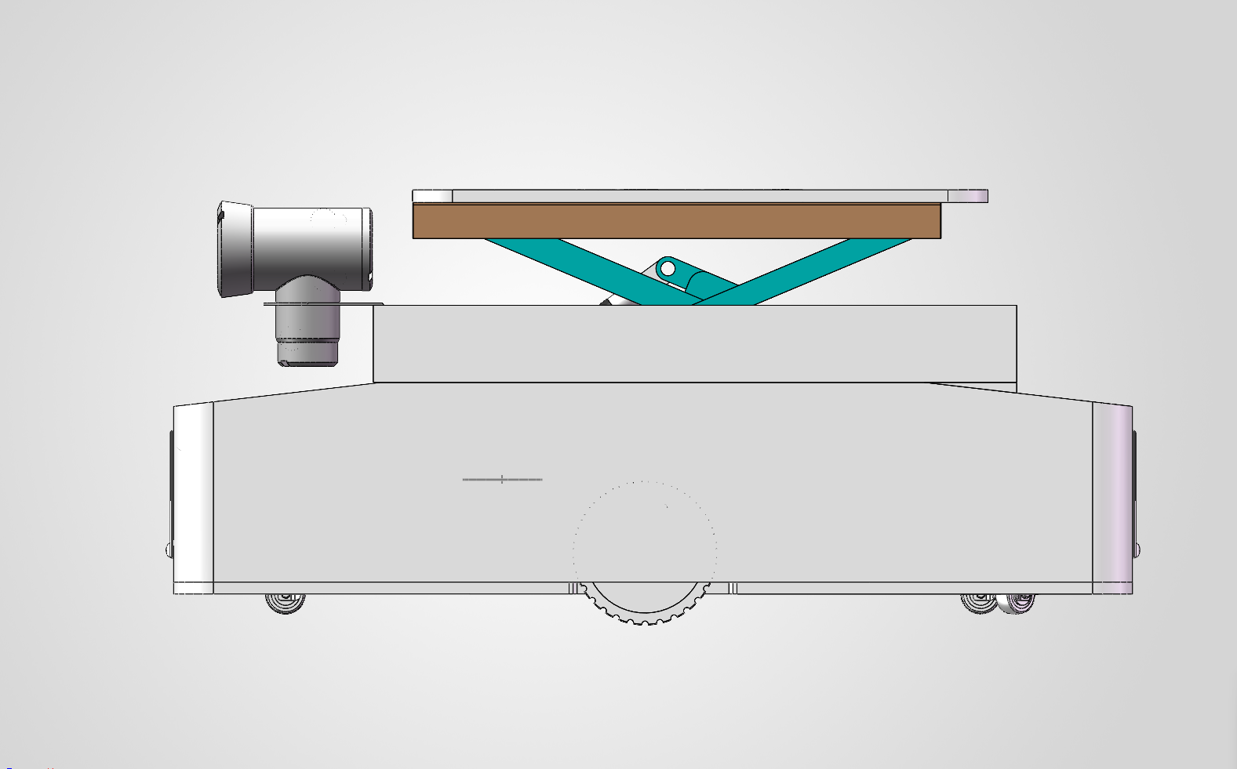
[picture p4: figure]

图 3-1 智能仓储移动机器人总体结构示意图

### 3.1 剪叉式垂直升降机构设计

剪叉式垂直升降机构是本文所设计智能仓储移动机器人的核心功能模块，承担货物

的垂直搬运任务。与固定高度的搬运平台相比，引入升降机构后，机器人可以在不改变

自身位置的情况下完成货物在不同高度货架层之间的取放操作，显著拓展了作业范围和

场景适应性。

### 3.1.1 机构选型依据

在仓储搬运场景中，升降机构需同时满足以下要求：（1）承载能力不低于 50 kg；（2）

升降行程覆盖仓库常用货架高度范围；（3）平台在升降全过程中保持水平姿态；（4）机

构收起时占用高度尽可能小，以利于机器人通过低矮空间；（5）结构简单、可靠性高、

制造成本可控。

经过对丝杆升降机构、液压升降机构、同步带升降机构和剪叉式升降机构等常见方

案的综合比较，本文选定剪叉式垂直升降机构。该机构利用两组交叉铰接的等长臂杆构

成剪叉单元，通过改变臂杆间夹角实现平台的高度调节。其优势在于：结构紧凑，折叠

高度低，能够获得较大的升程比；平台水平度保持性好，无须额外调平机构；承载能力

通过增减剪叉层数和调整臂杆截面可灵活配置；采用电机经减速器驱动底部滑动端时，

具备良好的可控性和定位精度。

### 3.1.2 机构结构组成

本文设计的单层剪叉式垂直升降机构如图3-2所示，主要由以下构件组成：

1. 剪叉臂杆——两根等长臂杆（各 600 mm，销孔中心距）在中点处通过中心铰轴

交叉连接，构成一个剪叉单元。臂杆采用 36 mm × 4.8 mm 的 Q235 实心扁钢，宽

面竖直布置以提供抗弯刚度。

2. 底座固定铰座——位于机构底部左侧，将臂杆 A 的下端与车体框架刚性铰接，约

束水平和竖直方向的平动自由度，仅允许绕铰轴的转动。

3. 底座滑动导轨——位于机构底部右侧，为臂杆 B 的下端提供水平滑动导向。滑动

端通过滑块在导轨槽内直线运动，以适应升降过程中臂杆投影长度的变化。

4. 顶部固定铰座——臂杆 B 的上端与承载平台底部铰接，约束平动自由度。
5. 顶部滚轮机构——臂杆 A 的上端通过两个滚轮在承载平台底部的导向槽内滚动，

以滚动摩擦代替滑动摩擦，降低运动阻力并提高升降平稳性。

6. 中心铰轴——连接两根臂杆的中点，传递两臂之间的相互作用力，直径 18 mm，

材料为 45 号钢。

7. 承载平台——660 mm × 312 mm × 3 mm 的 Q235 钢板，作为货物直接承载面。

图 3-2 剪叉式垂直升降机构三维模型

各铰接点均采用直径为 18 mm 的 45 号钢圆柱销作为连接件，配合耳板构成转动副。

所有焊接节点均经过去应力处理，以减少焊接残余变形对装配精度的影响。

3.1.3 材料选择

剪叉臂杆选用 Q235 普通碳素结构钢，其主要性能参数如表3-1所示。Q235 钢屈服强

度为 235 MPa，抗拉强度为 375 MPa，延伸率不低于 26%，弹性模量约为 2.06 × 10⁵ MPa，

具有良好的焊接性能和常温冲击韧性。该材料在机械制造行业应用广泛，采购成本较低，

加工工艺成熟，能够满足本设计的承载需求。销轴选用 45 号优质碳素结构钢，屈服强

度为 355 MPa，表面经调质处理以提高耐磨性。承载平台和底座板选用 Q235 钢板，与

臂杆材料保持一致，便于焊接和整体加工。

表 3-1 Q235 钢的主要性能参数
性能指标 | 数值范围/说明
屈服强度 σs | ≥ 235 MPa
抗拉强度 σb | 375 ∼ 500 MPa
延伸率 δ | ≥ 26%
弹性模量 E | ≈ 2.06 × 10⁵ MPa
密度 ρ | 7.85 g/cm³
泊松比 ν | 0.3
焊接性能 | 良好
冲击韧性 | 常温下具有良好韧性

### 3.2 升降机构工作原理与运动学分析

剪叉式垂直升降机构的工作原理基于平面连杆机构的运动特性。两组等长臂杆在中

心铰点处交叉连接，当底部滑动端在驱动力作用下水平移动时，两臂之间的夹角发生变

化，进而带动顶部平台沿竖直方向上下运动。

3.2.1 运动学建模

建立如图3-3和图3-4所示的机构运动简图。设单根臂杆长度为 L（销孔中心距），两

臂间夹角为 α，则臂杆与水平面的夹角（以下简称水平半角）为 β = α/2。以底部固定铰

点为坐标原点，水平方向为 X 轴，竖直方向为 Z 轴，可建立以下运动学关系。

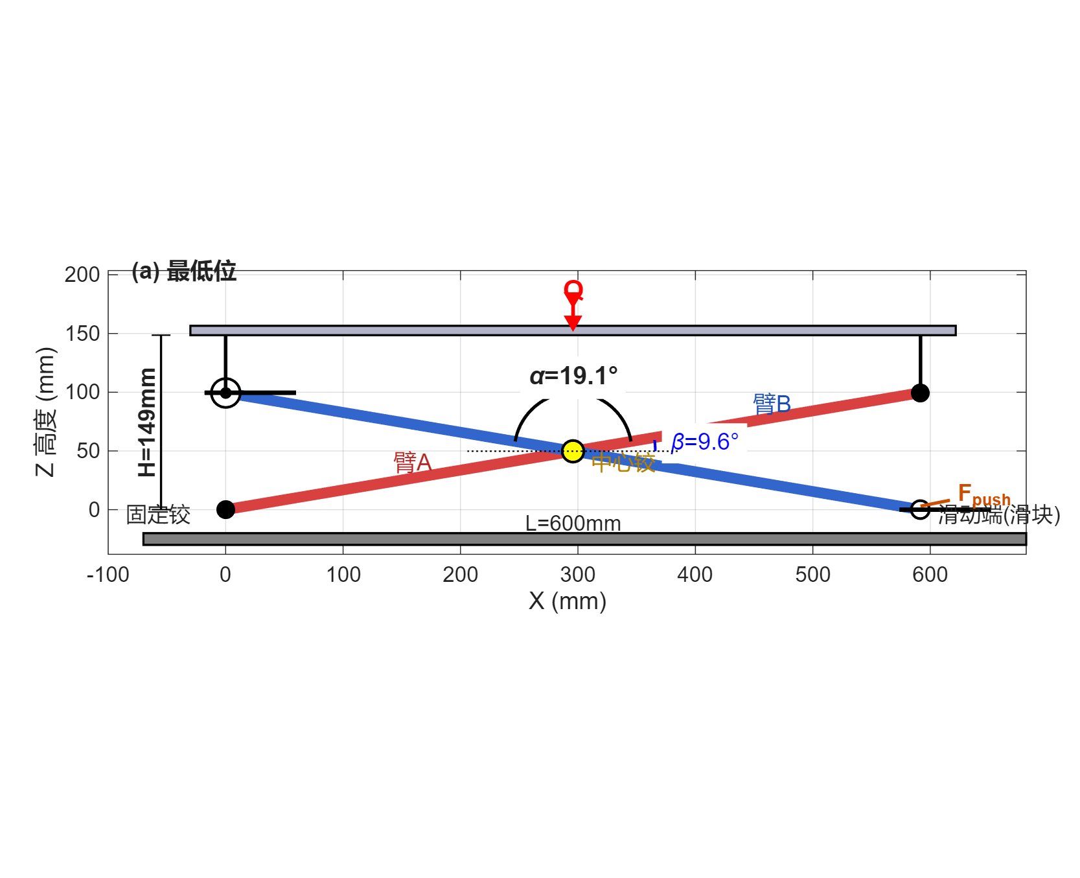
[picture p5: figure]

图 3-3 剪叉式升降机构运动简图（最低位）

如图3-4所示为最高位状态，两臂夹角增大至 αmax = 133.49◦，平台升至最高位置。

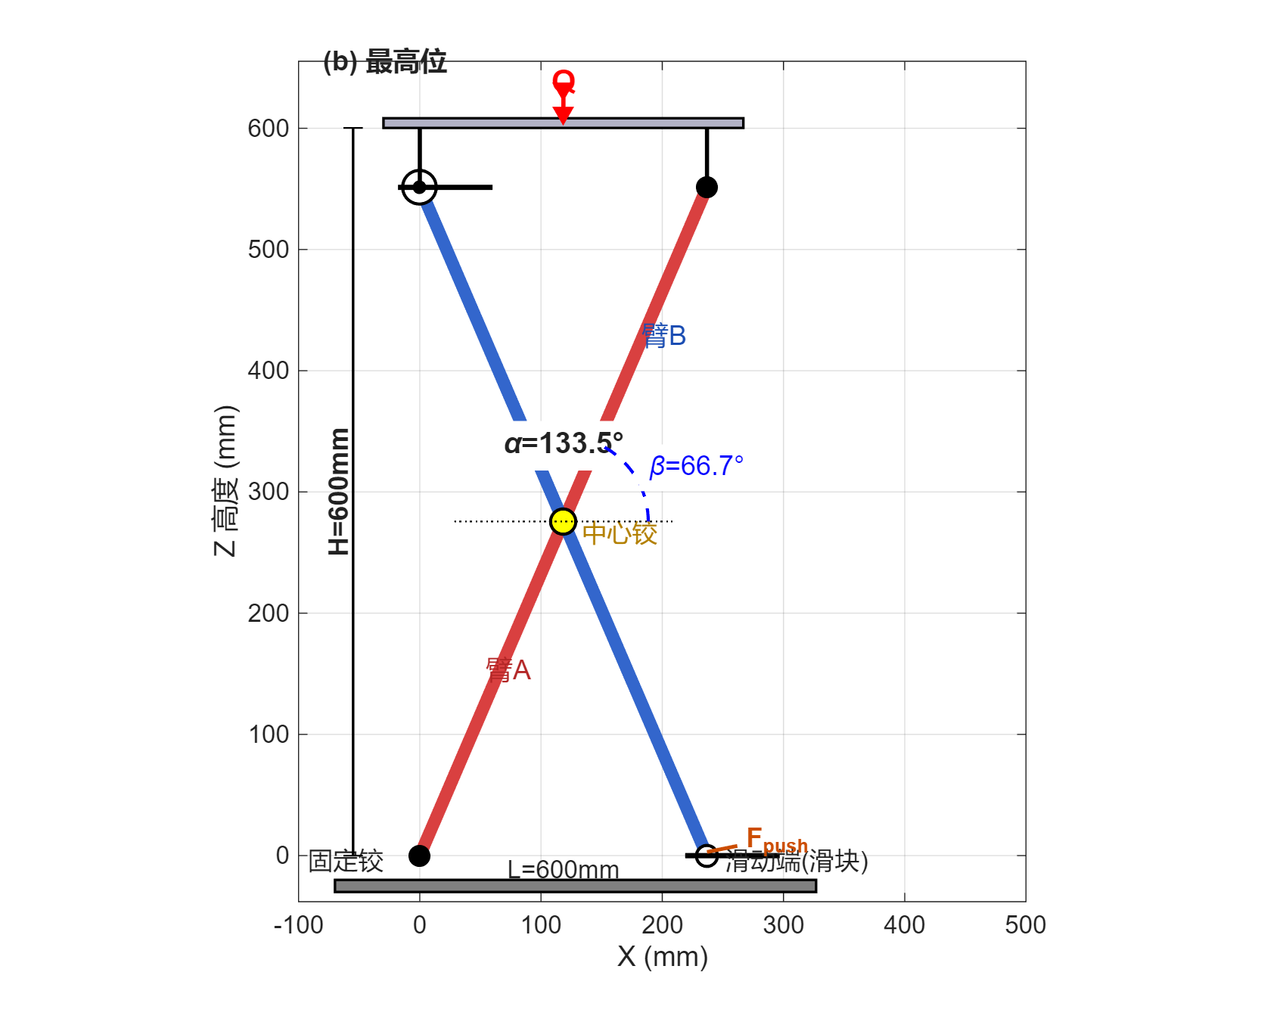
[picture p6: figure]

图 3-4 剪叉式升降机构运动简图（最高位）

台面高度 H 与水平半角 β 之间的关系为：
H = L · sin β + h0 = L · sin
α
2
+ h0 | (3-1)

其中 h0 ≈ 49 mm 为臂杆两端配件（铰座、滚轮及连接件）对台面高度的固定贡献

值。

底部滑动端的水平位移 xs 与 β 之间的关系为：

xs = L · cos β | (3-2)

由式 (3-1) 和 (3-2) 消去 β，可得台面高度与滑动端位移之间的非线性关系：

H =

q
L

2 − x
2
s + h0 | (3-3)

3.2.2 工作参数

本设计中，臂杆长度 L = 600 mm（不含两端配件）。在最低工作位置，两臂夹角

αmin = 19.10◦，对应水平半角 βmin = 9.55◦；在最高工作位置，两臂夹角 αmax = 133.49◦，

对应水平半角 βmax = 66.75◦。由式 (3-1) 计算得：

Hmin = 600 × sin(9.55◦
) + 49 ≈ 149 mm | (3-4)

Hmax = 600 × sin(66.75◦
) + 49 ≈ 600 mm | (3-5)

理论最大升程约为 452 mm，覆盖常用仓库货架的底层至中层取放需求。

### 3.3 升降机构受力分析与载重计算

### 3.3.1 额定载重设定

综合考虑智能仓储移动机器人的应用场景——中小型零件、料箱和半成品的垂直搬

运——以及整车自重、底盘稳定性和驱动能力等因素，将承载平台的额定载重设定为

Q0 = 50 kg，取重力加速度 g = 9.81 m/s

2。对应的额定载荷力 F 为：

F = Q0 · g = 50 × 9.81 ≈ 490.5 N | (3-6)

在强度校核中，将以此额定载荷为基准，并引入安全系数以确保结构在冲击和偏载

等异常工况下仍具有足够的承载能力。

### 3.3.2 剪叉臂受力分析

取最危险工况——平台位于最低位置（βmin = 9.55◦）——进行受力分析。此时臂杆

最接近水平状态，轴向力最大。

平台总载荷 F 通过顶部四个铰接点传递至两根臂杆。假定载荷均匀分配，每个顶部

铰接点承受 F/4 的竖直力。在顶部固定铰接点处，臂杆轴向力 Farm 的竖直分量与铰点载

荷平衡：

Farm · sin β =

F
4

(3-7)

由此得单根臂杆的轴向力表达式为：

Farm =

F
4 · sin β

(3-8)

代入数值 βmin = 9.55◦、F = 490.5 N：

Farm =

490.5
4 × sin(9.55◦
)
≈ 739.1 N | (3-9)

该轴向力以压缩形式作用于臂杆，同时臂杆还承受由自重引起的弯曲载荷。记材料

密度为 ρ、臂杆截面面积为 A、重力加速度为 g，则臂杆自重线载荷 w 为：

w = ρ · A · g = 7.85 × 10⁻⁶
kg/mm³ × 172.8 mm² × 9.81 m/s

2 ≈ 0.0133 N/mm (3-10)

将臂杆简化为两端铰支的简支梁，自重产生的跨中最大弯矩为：

Mself =

w· L

2
- cos β
8

≈

0.0133 × 600² × cos(9.55◦
)
8
× 10⁻³ ≈ 0.59 N·m | (3-11)

此外，考虑制造和装配过程中不可避免的偏心误差，保守取偏心距 e = 2 mm，其引

起的附加弯矩为：

Mecc = 0.5 · Farm · e = 0.5 × 739.1 × 0.002 ≈ 0.74 N·m | (3-12)

综合弯矩最大值为 Mmax ≈ 1.33 N·m。

### 3.3.3 各工作角度下的受力变化

平台在不同高度位置时，臂杆水平半角 β 发生变化，导致臂杆轴向力相应改变。

表3-2列出了额定载荷下各典型工作角度对应的受力值。

表 3-2 不同工作角度下的受力对比（Q0 = 50 kg）
两臂夹角 α（◦） 半角 β（◦） | 台面高度 H（mm） 臂轴向力 Farm（N）
19.10 | 9.55 | 149 | 739.1
20.00 | 10.00 | 153.2 | 706.2
30.00 | 15.00 | 204.3 | 473.8
40.00 | 20.00 | 254.2 | 358.5
50.00 | 25.00 | 302.6 | 290.2
133.49 | 66.75 | 600 | 133.5

由表可见，臂杆轴向力随平台升高（β 增大）而显著减小，最低位时臂杆轴向力达

到最大值 739.1 N，约为最高位时的 5.5 倍。因此在机构设计时应以最低位工况作为最危

险工况进行强度校核。

### 3.4 关键部件强度校核

本节在上述受力分析的基础上，对剪叉式升降机构的关键承载部件——剪叉臂杆、

铰接销轴和承载平台——逐一进行强度校核，以验证其在额定载荷下的安全性。

### 3.4.1 剪叉臂杆截面特性

臂杆采用 36 mm × 4.8 mm 的 Q235 实心扁钢，设截面宽度为 B = 4.8 mm、截面高度

为 H = 36 mm，宽面沿竖直方向布置以增强抗弯能力。其截面面积 A、强轴惯性矩 I强

（竖直面内弯曲）、弱轴惯性矩 I弱（侧向弯曲）、抗弯截面模量 W 以及最小回转半径 imin

计算如下：

A = B · H = 4.8 × 36 = 172.8 mm² (3-13)

I强 =

BH³
12

=

4.8 × 36³
12
≈ 18662 mm⁴ （竖直面内弯曲） | (3-14)

I弱 =

HB³
12

=

36 × 4.8
3
12
≈ 332 mm⁴ （侧向弯曲） | (3-15)

W =

I强
H/2

=

18662
18
≈ 1037 mm³ | (3-16)

imin =

r
I弱
A

=

r
332
172.8
≈ 1.39 mm | (3-17)

### 3.4.2 臂杆压弯组合强度校核

在轴向压力与弯矩的共同作用下，臂杆处于压弯组合应力状态。已算得臂杆轴向力

Farm = 739.1 N、截面面积 A = 172.8 mm²，则轴向压应力 σa 为：

σa =

Farm
A

=

739.1
172.8
≈ 4.28 MPa | (3-18)

已算得综合弯矩最大值 Mmax = 1.33 N · m = 1.33 × 10³ N · mm、抗弯截面模量 W =

1037 mm³，考虑自重弯矩和偏心弯矩，弯曲正应力 σb 为：

σb =

Mmax
W

=

1.33 × 10³
1037
≈ 1.28 MPa | (3-19)

截面上两应力叠加，压弯组合最大应力 σmax 出现在截面受压侧边缘：

σmax = σa + σb = 4.28 + 1.28 = 5.56 MPa | (3-20)

取安全系数 ns = 1.5，Q235 钢屈服强度 σs = 235 MPa，则许用应力 [σ] 为：

[σ] =

σs
ns

=

235
1.5
≈ 156.7 MPa | (3-21)

σmax = 5.56 MPa ≪ [σ] = 156.7 MPa，臂杆强度满足设计要求，应力利用率仅为 3.5%，

具有充足的安全余量。

### 3.4.3 臂杆屈曲稳定性校核

臂杆为细长受压构件，需校核其整体稳定性。由于臂杆截面为扁钢，弱轴方向（侧

向，I弱 = 332 mm⁴）的惯性矩远小于强轴方向（竖直面内，I强 = 18662 mm⁴），因此侧

向屈曲是稳定性的控制因素。

将臂杆简化为两端铰支的压杆，长度系数 µ = 1.0，有效长度 Leff = µL = 600 mm。弱

轴方向的长细比为：

λ =

Leff

imin

=

600
1.39
≈ 431.7 | (3-22)

Q235 钢的比例极限长细比约为 λp ≈ 104。由于 λ = 431.7 > λp，该杆属于大柔度压杆，

其临界载荷采用欧拉公式计算（E = 2.06 × 10⁵ MPa 为 Q235 钢弹性模量，I弱 = 332 mm⁴

为弱轴惯性矩，Leff = 600 mm 为有效长度）：

Fcr =

π

2EI弱

L

2
eff

=

π

2 × 2.06 × 10⁵ × 332
600²
≈ 1874 N | (3-23)

取屈曲稳定安全系数 nbuckle = 3.0，则：

nactual =

Fcr

Farm

=

1874
739.1
≈ 2.54 < 3.0 | (3-24)

上述计算表明，在无侧向约束的条件下，臂杆弱轴方向的安全系数 nactual ≈ 2.54 略

低于设计要求的 nbuckle = 3.0。为解决这一问题，本设计在两侧臂杆之间增设侧向支撑隔

套，将有效长度减半至 300 mm，此时：

F

′
cr =

π

2 × 2.06 × 10⁵ × 332
300²
≈ 7496 N | (3-25)

n

′
actual =

7496
739.1
≈ 10.14 ≫ 3.0 | (3-26)

增设侧向支撑后，屈曲安全系数提升至 10.14，满足设计要求。因此，在实际结构中

必须设置中心隔套或侧向限位装置以防止臂杆发生侧向失稳。

### 3.4.4 铰接销轴强度校核

各铰接点采用直径 D = 18 mm 的 45 号钢圆柱销。销轴承受臂杆传递的轴向力，处

于双面剪切状态。45 号钢的屈服强度 σs = 355 MPa，按第四强度理论（von Mises 准则）

近似取剪切屈服强度 τy ≈ 0.6σs = 0.6 × 355 ≈ 213 MPa。取安全系数 ns = 1.5，许用剪应

力 [τ] 为 [τ] = 213/1.5 ≈ 142 MPa。

销轴截面面积：

Apin =

πD

2
4

=

π × 18²
4

≈ 254.5 mm²
(3-27)

双面剪切承载力：

Fpin = 2 · [τ] · Apin = 2 × 142 × 254.5 ≈ 72.3 kN | (3-28)

销轴剪切安全系数 n = Fpin/Farm = 72.3 × 10³

/739.1 ≈ 97.8，按额定工况剪叉机构受

力关系折算至台面，等效承载能力约 4890 kg，远超 50 kg 额定载重，销轴剪切强度满足

要求。

在对销轴在耳板间的弯曲变形进行校核时，耳板内间距实测为 Ls = 27 mm，销轴作

为简支梁，力作用于跨中，销轴跨中弯矩 Mpin、抗弯截面模量 Wpin 和弯曲应力 σpin 为：

Mpin =

Farm · Ls
4

≈

739.1 × 27
4
≈ 4.99 × 10³ N·mm | (3-29)

Wpin =

πD

3
32

=

π × 18³
32

≈ 572.6 mm³
(3-30)

σpin =

Mpin

Wpin

≈ 8.7 MPa ≪ [σ] = 236.7 MPa | (3-31)

耳板孔壁的承压应力为（耳板厚度 t = 6 mm）：

σbrg =

Farm
D · t

=

739.1
18 × 6
≈ 6.8 MPa | (3-32)

远低于 Q235 钢的许用承压应力（约 235 MPa），销轴及耳板连接强度均满足要求。

### 3.4.5 承载平台强度校核

承载平台为 660 mm × 312 mm × 3 mm 的 Q235 矩形薄板，设平台长度 a = 660 mm、

平台宽度 b = 312 mm、板厚 t = 3 mm，四边通过螺栓与升降机构顶部框架简支连接。在

50 kg 均布载荷下，采用薄板弯曲的 Navier 级数解进行挠度和应力分析。

平台均布载荷 q（额定载荷力 F = 490.5 N 由式 (3-6) 算得，即 F = Q0 · g = 50×9.81）：

q =

F
a · b

=

490.5
660 × 312
≈ 2.38 × 10⁻³ MPa | (3-33)

板的弯曲刚度：

Dplate =

Et³
12(1 − ν
2
)

=

2.06 × 10⁵ × 3
3
12 × (1 − 0.3
2
)
≈ 5.09 × 10⁵ N·mm | (3-34)

采用四边简支矩形板的 Navier 级数解，取前 51 × 51 项求和，计算得平台中心的最

大挠度和应力为：

wmax ≈ 0.47 mm （挠跨比约为b/669） | (3-35)
σx,max ≈ 7.0 MPa, σy,max ≈ 16.2 MPa | (3-36)

σvm =

q
σ²

x + σ²

y − σxσy ≈ 14.1 MPa | (3-37)

σvm = 14.1 MPa < [σ] = 156.7 MPa，平台弯曲强度满足要求，利用率为 9.0%。平台

最大挠度为 0.47 mm，在仓储搬运精度允许范围内。为进一步提高平台刚度，后续可将

板厚增加至 4 mm，此时挠度可降至约 0.20 mm，应力降至约 7.9 MPa。

### 3.4.6 有限元数值验证

为进一步验证前述手算结果的可靠性，采用 MATLAB 编写有限元分析程序进行数

值建模与补充验证。臂杆采用 30 个平面梁单元离散，考虑轴向与弯曲耦合效应，施加

轴向压力 Farm = 739.1 N 及自重均布载荷，边界条件为两端铰支；台面板采用 Navier 级

数解取前 21 × 21 项计算全场挠度与应力分布。

有限元分析结果如图3-5和图3-6所示。由数值解可知：（1）臂杆最大轴向应力约

5.16 MPa、最大弯曲应力约 0.44 MPa，组合应力约 5.60 MPa，与理论手算值 5.56 MPa 吻

合（偏差 < 1%）；（2）臂杆最大横向挠度约 0.08 mm，变形量极小；（3）台面板中心

挠度约 0.47 mm、von Mises 等效应力约 14.1 MPa，与解析解一致；（4）加设中心隔套

后弱轴屈曲安全系数提升至约 10.1，满足 n ≥ 3 的设计要求。各部件应力均远低于 Q235

许用应力 156.7 MPa，销轴弯曲应力（< 10 MPa）与耳板承压应力（< 7 MPa）同样充裕。

图 3-5 臂杆 FEA 应力沿长度分布

从应力分布曲线可以看出，臂杆最大轴向应力约 5.16 MPa，出现在截面中心附近；

最大弯曲应力约 0.44 MPa，位于截面边缘。二者叠加后的组合应力约 5.60 MPa，与第三

章理论手算值 5.56 MPa 的偏差不足 1%，验证了强度校核方法的正确性。此外，臂杆最

大横向挠度仅约 0.08 mm，变形量极小，表明结构具有足够的刚度。

为进一步直观展示各关键部件的应力水平，图3-6给出了臂杆、销轴、承载平台和

耳板四类部件的最大应力对比。由图可见，各部件应力均远低于 Q235 钢的许用应力

156.7 MPa，其中应力利用率最高的承载平台也仅为 9%，销轴弯曲应力不足 10 MPa，耳

板承压应力不足 7 MPa，各连接部位同样具有充裕的安全裕度。

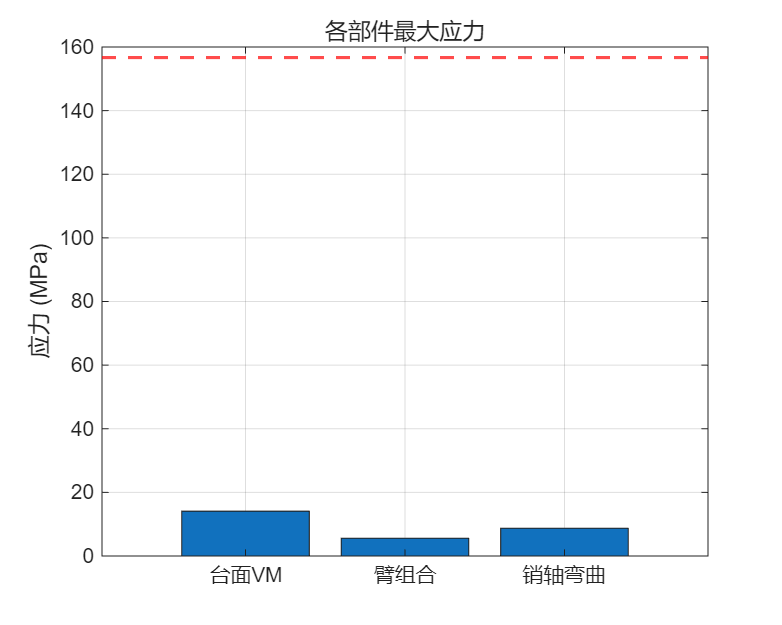
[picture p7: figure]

图 3-6 各部件最大应力对比

综合有限元数值解与理论手算结果来看，二者在臂杆组合应力、台面板挠度与应力、

屈曲安全系数等各项指标上高度吻合，相互印证了第三章强度校核方法的正确性，同时

也进一步确认了所设计剪叉式升降机构在 50 kg 额定载荷下具有充足的安全裕度。

3.5 小结

本章完成了智能仓储移动机器人剪叉式垂直升降机构的机械结构设计与强度校核。

首先介绍了剪叉式升降机构的选型依据和结构组成，建立了运动学模型，推导了台面高

度与臂杆角度之间的数学关系。在此基础上，进行了额定载重设定和受力分析，确定了

最危险工况下各关键部件的载荷状态，并对臂杆、销轴和承载平台分别进行了强度校核

和稳定性分析。主要结论如下：

（1）剪叉式升降机构采用单层剪叉方案，臂长 L = 600 mm（不含两端配件），截面

为 36 mm × 4.8 mm 的 Q235 实心扁钢，两臂夹角范围为 19.10◦ ∼ 133.49◦。计入两端配件

高度（h0 ≈ 49 mm）后，台面距升降底座高度约 149 ∼ 600 mm，理论升程约 452 mm，行

程覆盖常用货架高度范围。

（2）额定载重设定为 50 kg，在最危险工况（最低位，β = 9.55◦）下，臂杆轴向力为

739.1 N，组合应力约 5.56 MPa，远低于 Q235 钢的许用应力 156.7 MPa（利用率 3.5%）；

弱轴方向屈曲临界载荷约 1.87 kN，在增设侧向支撑隔套后有效长度减半，安全系数提

升至 n ≈ 10.1，满足稳定性设计要求。

（3）铰接销轴（直径 18 mm）的双面剪切承载力约 72.3 kN，折合等效载荷远超额定

值；销轴弯曲应力约 8.7 MPa，耳板承压应力约 6.8 MPa，均在安全范围内。

（4）承载平台在 50 kg 均布载荷下最大挠度约 0.47 mm，von Mises 等效应力约

14.1 MPa，满足刚度与强度要求。

（5）采用 MATLAB 梁单元 FEA 与台面板 Navier 级数解对上述手算结果进行数值验

证。臂杆组合应力有限元解约 5.60 MPa，与理论值 5.56 MPa 偏差 < 1%；台面板挠度与

应力、销轴强度及屈曲安全系数等均与手算结果一致，验证了理论校核方法的正确性。

综合以上分析，本文所设计的剪叉式垂直升降机构在强度、刚度和稳定性方面均满

足 50 kg 额定载重的设计要求，且具有较大的安全余量。理论手算与有限元数值解高度

吻合（臂杆组合应力偏差 < 1%），相互印证了校核结果的可靠性。根据实际设计参数，

上述计算结果可进一步通过样机试验进行最终验证。

## 第 4 章 智能仓储移动机器人电气系统设计

### 4.1 电气系统总体架构

智能仓储移动机器人的电气系统涵盖电源系统、驱动系统、传感器系统和控制系统

四个板块。电源系统为整车各模块提供稳定可靠的电能供应，选用锂离子电池组作为

主电源，经由 DC-DC 变换器为不同电压等级的子系统供电，以满足长时间连续运行的

需要；驱动系统由伺服电机和配套驱动电路构成，采用交流伺服电机配合行星减速器，

以确保速度和位置控制精度；传感器系统包含红外传感器、超声波传感器和编码器三

类，红外传感器负责近距离循迹和避障，超声波传感器负责中远距离测距，电机自带的

增量式编码器用于轮速测量和航位推算，为运动控制提供本体状态反馈；控制系统以

STM32F103C8T6 微控制器为核心，承担传感器数据采集、控制算法执行、驱动信号输

出等职责，协调各子系统的工作，实现自主导航和避障功能。以上四个子系统各司其职

又紧密协作，共同保障智能仓储移动机器人能够安全高效地完成仓储环境中的物料搬运

任务。

### 4.1.1 智能仓储移动机器人主控制器选择

在智能仓储移动机器人的电气系统设计中，主控制器的选型是整套方案能否落地的

关键环节。综合权衡性能、成本和开发难度等因素后，选定 STM32F103C8T6 芯片作为

主控单元。该芯片基于 ARM Cortex-M3 内核，运算能力较好、功耗较低、外设接口丰

富，能够满足智能仓储移动机器人在导航和避障方面的需求，图4-1为其芯片实物图。

图 4-1 STM32F103C8T6 芯片实物图

该控制器主频为 72 MHz，配备 64 KB 程序存储和 20 KB 的 RAM，能够支撑较复杂

的算法运行，同时兼容 USART、SPI、I2C 等多种通信接口，便于与传感器和电机驱动

器进行数据交换。加之 37 个 I/O 口和 12 位 ADC 等资源，开发和扩展都较为便利。

表 4-1 STM32F103C8T6 芯片参数表
参数 | 数值
CPU 内核 | ARM Cortex-M3
CPU 最大主频 | 72 MHz
CPU 位数 | 32 Bit
程序存储容量 | 64 KB
程序存储器类型 | FLASH
RAM 容量 | 20 KB
I/O 数量 | 37
ADC(位数) | 12 bit

图4-2为 stm32f103c8t6 芯片的原理图。

图 4-2 STM32F103C8T6 芯片示意图

### 4.2 电机，传感器等部件选型

4.2.1 电机选型

在小车的电机选型过程中，由于本设计采用差速驱动方式，且搬运小车对定位精度

和低速平稳性有较高要求，因此驱动电机不仅要提供足够的牵引力，还应具备良好的调

速性能和一定的功率裕量。根据设计要求，搬运车最大牵引线速度为 30m/min，驱动轮

直径为 180mm，则驱动轮转速可由式(4-1)计算得到：

N =

V
πD

(4-1)

其中，V = 30 m/min = 30000 mm/min，D = 180 mm。为使计算过程中单位保持一

致，同时也便于后续与减速箱输出转速对应，此处先将搬运车的最大牵引线速度换算为

毫米每分钟，再代入式(4-1)进行计算；驱动轮直径取 180mm，兼顾通过性、承载能力与

车体紧凑布置的要求。代入可得：

N =

V
πD

=

30 × 1000
π × 180
| ≈ 53.05 r/min | (4-2)

由式(4-2)可知，减速箱输出端对应的转速约为 53.05 r/min。进一步分析驱动负载，

已知整车自重约 200 kg，额定搬运质量为 50 kg，满载总质量约 250 kg。综合考虑轮面

滚动摩擦、轴承阻力、地面不平整引起的附加阻力等因素，取综合阻力系数 µ = 0.2，取

重力加速度 g ≈ 10 m/s
2 估算，车辆匀速运行时需克服的总阻力 f 如式(4-3)所示：
f = µ · m · g = 0.2 × 250 × 10 = 500 N | (4-3)

由于整车采用双轮差速驱动结构，匀速行驶时两侧驱动轮能够较为均匀地分担整车

载荷，故每个驱动轮承担的牵引力可近似视为总牵引力的一半，以便后续计算驱动轮输

出转矩和电机功率。单个驱动轮所需牵引力近似为式(4-4)：

F =

f
2
= 250 N | | (4-4)

以驱动轮半径 R = 90 mm = 0.09 m 进行计算，将单个驱动轮所需承担的牵引力转换

为对应的输出转矩。该参数表示驱动电机在减速箱输出端需要提供的扭矩，是保障小车

在满载工况下平稳起步、匀速行驶以及克服滚动阻力的关键依据。单个驱动轮输出转矩

如式(4-5)所示：

M = F × R = 250 × 0.09 = 22.5 N · m | (4-5)

获得驱动轮输出转矩后，还需进一步估算驱动轮侧的理论机械功率。依据机械功率

Pw（kW）与转矩 M（N · m）、转速 n（r/min）之间的关系 Pw = M · n/9550，其中常数

9550 = 60 × 1000/(2π) 为工程单位换算系数。将驱动轮输出转矩 M = 22.5 N · m 和驱动

轮转速 n = 53.05 r/min 代入，驱动轮侧的理论机械功率 Pw 如式(4-6)所示：

Pw =

M × n
9550 =

22.5 × 53.05
9550 | ≈ 0.125 kW | (4-6)

由于实际传动过程中减速箱、联轴器和轴承等部件均会带来一定的机械损耗，理论

机械功率无法直接作为电动机的选型依据。若考虑减速箱与传动机构效率 η = 0.95，则

电动机所需额定功率还需在理论功率基础上加以修正，以确保电机在启动、加速和负载

波动等工况下仍具备充足的功率余量。电动机所需额定功率如式(4-7)所示：

Pm =

Pw
η

=

0.125
0.95 ≈ 0.132 kW | (4-7)

由计算结果可知，理论所需功率约为 0.13kW。综合额定功率、输出转矩、控制精

度和减速比匹配等因素，最终选用额定功率为 400 W 的伺服电机 SMC80S-0040-30AoK-

3DKH 作为驱动电机。该电机额定转速为 3000 r/min，额定转矩为 1.27 N · m，配合减速

箱后能够满足驱动轮所需的低速大扭矩输出要求，并为启动、加速和负载波动预留了充

足的动力余量；其理论总减速比如式(4-8)所示：

i =

n1
n2

=

3000
53.05 ≈ 56.55 | (4-8)

需要说明的是，上述选型计算主要基于匀速行驶时的滚动阻力工况。实际运行中，

小车还面临以下动态载荷情形：(1) 起步与制动阶段的惯性加速力，以 0.3 m/s | 2 加速度

估算，附加惯性力约 Fa = ma = 250 × 0.3 = 75 N，折算到单轮约增加附加惯性转矩

Ma = Fa · R/2 = 75 × 0.09/2 ≈ 3.38 N · m；(2) 差速转弯时外侧轮承载增大，极端情况下载

荷偏移约 10%∼15%；(3) 举升过程中搬运物抬升导致重心上移，对驱动轮法向力的影响有

限但需考虑；(4) 地面不平整引起的附加载荷波动。综合上述工况，实际峰值转矩需求约

为稳态值的 1.3∼1.5 倍，即约 29 ∼ 34 N · m。所选电机配合实际选用的 40 倍减速比（详见

减速器选型小节）后的峰值输出转矩 Tpeak 为 Tpeak = Tn · λ · i = 1.27 × 3 × 40 ≈ 152.4 N · m，

其中 λ 为伺服电机过载系数（一般为 3 倍额定转矩，此处取 λ = 3），Tn 为额定转矩，

远高于动态峰值需求，具备充足的动力余量。因此，所选伺服电机能够满足搬运车 30

m/min 的最高行驶速度要求以及各类工况下的牵引需求。相关型号参数如表格4-2所示。

所选 SMC80S-0040-30AoK-3DKH 伺服电机满足本设计的功率与转矩需求。其电机

外形图如图4-3所示。

图 4-3 SMC80S-0040-30AoK-3DKH 伺服电机外形图

表 4-2 SMC 系列伺服电机技术参数

伺服电机型号

SMC60S-0020-30
AoK-3DKH

SMC60S-0040-30
AoK-3DKH

SMC80S-0040-30
AoK-3DKH

SMC80S-0075-30
AoK-3DKH

适配驱动

FD123-LA-000
FD123-CA-000
FD123-CC-000
FD123-EA-000

FD123-LA-000
FD123-CA-000
FD123-CC-000
FD123-EA-000

FD133-LA-000
FD133-CA-000
FD133-CC-000
FD133-EA-000

FD133-LA-000
FD133-CA-000
FD133-CC-000
FD133-EA-000
直流母线电压 UDC | 48 | 48 | 48 | 48

连续
特性
额定功率 Pn(W) | 200 | 400 | 400 | 750
额定转矩 Tn(Nm) | 0.64 | 1.27 | 1.27 | 2.39
额定转速 nN(rpm) | 3000 | 3000 | 3000 | 3000
额定电流 In(A) | 4.6 | 10 | 9.6 | 21.5
瞬时最大转矩 Tm(Nm) | 1.92 | 3.81 | 3.81 | 7.17
瞬时最大电流 Im(A) | 13.8 | 25 | 24 | 64.5
连续静态转矩 Ts(Nm) | 0.7 | 1.4 | 1.4 | 2.63
连续静态电流 Is(A) | 5.06 | 11 | 10.6 | 23.7
线-线电阻 RL
(Ω) | 1.1 | 0.42 | 0.22 | 0.1
线-线电感 LL(mH) | 2.4 | 0.79 | 1 | 0.46
机械时间常数 (ms) | 3.22 | 1.84 | 1.65 | 1.79
反电势常数 Ke(V/krpm) | 9 | 8 | 8 | 6.7
位置反馈装置 | 2500ppr 光电式编码器（增量式）
冷却方式 | 全封闭，自冷却

4.2.2 减速器选型

依据前述计算结果，驱动电机的额定转速为 n1 = 3000 r/min，驱动轮在满足整车最

高行驶速度要求时对应的转速为 n2 = 53.05 r/min。据此，电机输出端与驱动轮之间所需

的理论总传动比可按式：

i =

n1
n2

=

3000
53.05 ≈ 56.55 | (4-9)

进行计算。不难看出，要将电机输出转速降至驱动轮所需范围，同时保证输出扭矩

满足满载运行要求，必须配置具有较大减速比的减速器。考虑到小车本身结构紧凑、安

装空间有限，且对传动平稳性、输出精度和维护便利性要求较高，故不宜采用多级串联

式减速方案，而应优先选用体积较小、传动效率较高、减速比范围较宽的标准化减速器。

综合传动比匹配、安装布置和产品系列的可获得性，最终选定 ZJPX 系列精密行星

减速机作为电机与驱动轮之间的减速装置。相较于普通减速方案，这类减速机结构更紧

凑、传动更平稳，也更适合安装空间有限的移动机器人平台。其主要优点如下：

1. 采用齿轮啮合传动，输出扭矩较大，传动效率高，且运行噪声小，适合对平稳性

要求较高的移动机器人系统；

2. 传动过程中受力分布较均匀，能够改善整机运行的稳定性，减少冲击和振动对机

构的影响；

3. 结构紧凑，输入端与输出端的连接方式灵活，便于与伺服电机组合安装，整体装

配可靠性高；

4. 日常维护简单，润滑条件较稳定，能够满足小车长期连续运行的使用需求。

ZJPX 系列精密行星减速机的主要技术参数如表4-3所示。

表 4-3 ZJPX 行星减速机技术参数
产品
型号 | ZJPX65 | ZJPX85 | ZJPX115 | ZJPX142 | 单位 | 级数

最大
径向力 | 1550 | 3055 | 4330 | 9480 | N
最大
轴向力 | 1220 | 2330 | 3300 | 6800 | N

满载
效率

95

| | | | | % | 1 级
93 | 2 级
90 | 3 级
平均
寿命 | | | 20000 | | h

根据减速器资料，ZJPX115 型二级精密行星减速器额定输出扭矩为 90 N · m。所选

SMC80S 伺服电机额定转矩 1.27 N · m 经 40 倍减速后连续输出扭矩约 1.27 × 40 × 0.93 ≈

47.2 N · m（计入二级传动效率 93%），满足驱动轮 22.5 N · m 的需求且留有充足余量。结

合整车的安装空间、传动效率以及运行稳定性要求，最终确定采用该型号，减速比为 40。

该减速比与理论值 56.55 存在差异，工程实现中通过伺服驱动器限速进行补偿：当电机

最高转速限制在约 2122 r/min 时，减速后轮速约 53.05 r/min，对应线速度约 30 m/min，

可满足速度指标。

进一步分析该方案对控制性能的影响：从低速控制精度角度看，40 倍减速比下电

机每转对应驱动轮转动 9

◦，相比 56.55 倍减速比的 6.37◦，轮速分辨率略有降低，但由

于 SMC80S 伺服电机编码器分辨率达 17 位（131072 脉冲/转），经减速后轮速检测精度

仍可达 0.004 r/min，完全满足仓储机器人低速运行（0.1 ∼ 1.0 m/s）的控制需求。从启

动转矩角度看，40 倍减速比提供的输出扭矩（47.2 N · m）相比理论 56.55 倍减速比（约

66.5 N · m）虽有所降低，但仍为驱动轮所需扭矩（22.5 N · m）的 2.1 倍，启动加速能力

充足。此外，较小的减速比有利于降低传动链的回程间隙和弹性变形，反而可改善低速

段的响应平稳性。综上，该方案在满足速度与转矩指标的前提下，兼顾了控制精度与运

行平稳性，是一种合理的工程折中选择。

4.2.3 传感器选型

小车配备红外传感器和超声波传感器两种类型，二者在检测距离、响应速度和适用

场景方面各具优势，通过配合使用可实现互补。红外传感器基于光电反射原理，适合近

距离检测，具有响应速度快、体积小、成本低的特点，常用于地面循迹线检测；超声波

传感器基于声波飞行时间测距原理，适合中远距离障碍物检测，精度较高且不受光照条

件影响。两类传感器协同使用，分别承担循迹和避障功能，使小车对周围环境的感知更

加全面。

红外线传感器选用型号为 TCRT5000 的反射式红外传感器，如图4-4所示。

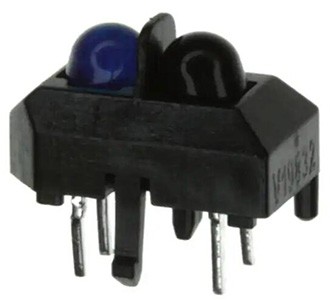
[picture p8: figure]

图 4-4 TCRT5000 红外传感器实物图

TCRT5000 是一种集发射与接收于一体的反射式光电传感器，由红外发光二极管和

NPN 光电三极管组成。其工作原理为：红外发射管向前方发射红外光，当遇到障碍物或

地面黑色引导线时，红外光被反射回来并由接收管检测，依据反射光强度判断前方是否

存在检测目标。本文选用带比较器电路的 TCRT5000 传感器模块，该模块板载 LM393 比

较器和电位器，可输出数字量（高低电平），直接连接 STM32 的 GPIO 引脚即可使用。

该模块的有效检测距离为 1 ∼ 25 mm，适合黑白线循迹检测；但对小车避障而言，25 mm

的检测距离不足以提供安全制动裕量，因此本文中 TCRT5000 主要用于地面轨迹线检测

（循迹），障碍物检测功能由测距范围更远的 HC-SR04 超声波传感器承担。

超声波传感器选用型号为 HC-SR04 的超声波测距模块，如图4-5所示。

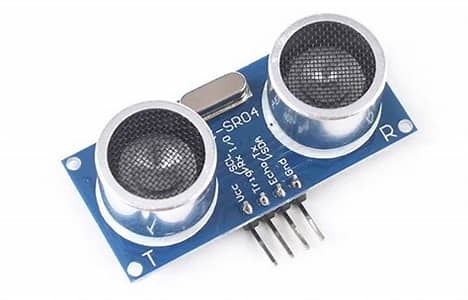
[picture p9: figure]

图 4-5 HC-SR04 超声波传感器实物图

该模块通过发射超声波脉冲并接收障碍物反射信号来测量距离。其工作过程为：

STM32 向 Trig 引脚发送一个不低于 10 µs 的高电平触发信号，模块随即发射一组 40kHz

的超声波脉冲，同时将 Echo 引脚置为高电平；当超声波遇到障碍物反射回来被接收

后，Echo 引脚恢复低电平，通过测量 Echo 高电平的持续时间即可计算出障碍物距离。

HC-SR04 工作电压为 5V，测距范围为 2cm 至 400cm，测量精度可达 3mm，适合小车在

仓储环境中进行中远距离障碍物检测。将该模块与 STM32 连接后，小车能够实时获取

前方障碍物的距离信息，与红外传感器的近距离检测相配合，使导航和避障功能更加完

善。

两种传感器协同工作，覆盖了小车在不同距离范围的感知需求，为后续运动控制提

供了可靠的数据支撑。

除环境感知传感器外，小车还需要获取自身运动状态。所选 SMC80S 伺服电机自带

增量式光电编码器，分辨率为 2500 P/R，经 4 倍频后每转输出 10000 个脉冲，可精确测

量左右轮的转速和转角。通过对编码器脉冲进行计数和微分运算，能够实时计算出各轮

的角速度和累计转角，进而由差速运动学方程推算出机器人的航向角变化量 ∆θ 和行驶

里程，构成航位推算（Dead Reckoning）系统。编码器信号通过 STM32 的定时器编码器

接口（TIMx_CH1/TIMx_CH2）以四倍频模式采集，无需额外的信号调理电路。该方案

在短距离、平坦地面条件下能够满足定位精度需求；若后续需要更高精度，可引入惯性

测量单元（IMU）进行航向角融合修正。

### 4.3 控制电路设计

4.3.1 STM32F103C8T6 最小系统

STM32F103C8T6 最小系统主要由电源电路、滤波电路、时钟电路、SWD 程序下载

调试电路和复位电路组成。如图4-6所示。

图 4-6 STM32F103C8T6 最小系统示意图

其中，电源电路采用 ME6211C33M5G-N 芯片（SOT-23-5 封装，输出 3.3V），配合

104 去耦电容滤除高频噪声，为 STM32 提供稳定供电。时钟电路采用 8MHz 外部晶振，

配合两个 12pF 起振电容。电源与时钟电路如图4-7所示。

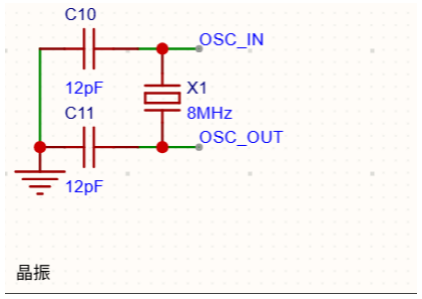
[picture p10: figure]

图 4-7 电源芯片（左）与时钟电路（右）

SWD 程序下载调试电路采用两线协议（SWDIO+SWCLK），配合 ST-Link 调试器

完成程序烧录和断点调试；复位电路通过按键拉低 NRST 引脚实现硬件复位，电容滤除

按键抖动。SWD 与复位电路如图4-8所示。

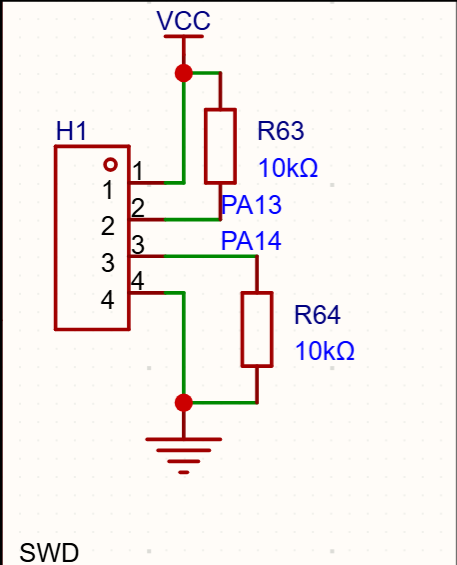
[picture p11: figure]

图 4-8 SWD 调试接口（左）与复位电路（右）

STM32F103C8T6 最小系统的设计涵盖了电源、滤波、时钟、SWD 调试和复位等关

键电路，为小车的运动控制和环境感知奠定了硬件基础。

### 4.3.2 传感器接口电路设计

传感器接口电路涵盖红外传感器接口和超声波传感器接口两部分，保障小车能够准

确获取环境信息。

红外传感器接口电路用于连接 TCRT5000，输出数字量直接连接 STM32 的 GPIO 引

脚，信号线加 10kΩ 上拉电阻和 100nF 去耦电容。超声波传感器接口电路连接 HC-SR04

模块，Trig 引脚（PA1）触发发射，Echo 引脚（PA2）接收反射信号。两类传感器接口如

图4-9所示。

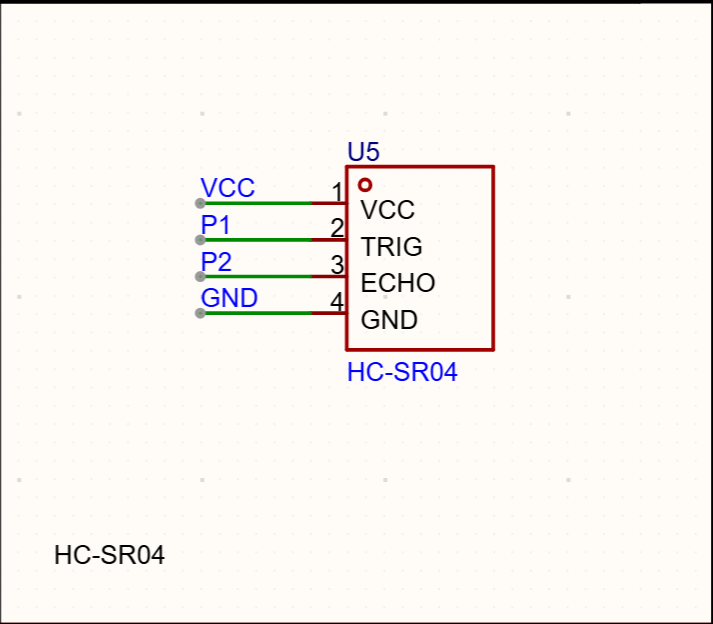
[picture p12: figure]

图 4-9 红外传感器接口（左）与超声波传感器接口（右）

红外传感器负责地面循迹线检测，超声波传感器负责中远距离障碍物测距，二者相

互配合，为循迹控制和避障决策提供数据支撑。

4.4 小结

本章完成了智能仓储移动机器人的电气系统设计，包括主控制器选型、驱动电机与

减速器匹配、红外与超声波传感器选型，以及最小系统和接口电路设计。上述设计为后

续的运动学建模、路径规划与控制算法实现提供了硬件基础。

## 第 5 章 智能仓储移动机器人运动学建模与仿真

在对智能仓储移动机器人的运动性能进行分析和控制之前，需要建立能够反映其结

构特性和运动约束的运动学模型。运动学模型描述的是机器人位姿（位置与姿态）随时

间的变化规律，不涉及力和力矩等动力学因素，是开展轨迹规划、速度控制和路径跟踪

的基础。对于本文所研究的双轮差速智能仓储移动机器人，其运动主要发生在二维平面

内，故可借助平面直角坐标和航向角建立运动学方程，为后续的轨迹仿真和控制器设计

提供数学基础。

所研究的智能仓储移动机器人为双轮差速移动机器人，模型如图5-1所示，下面展开

运动学分析。

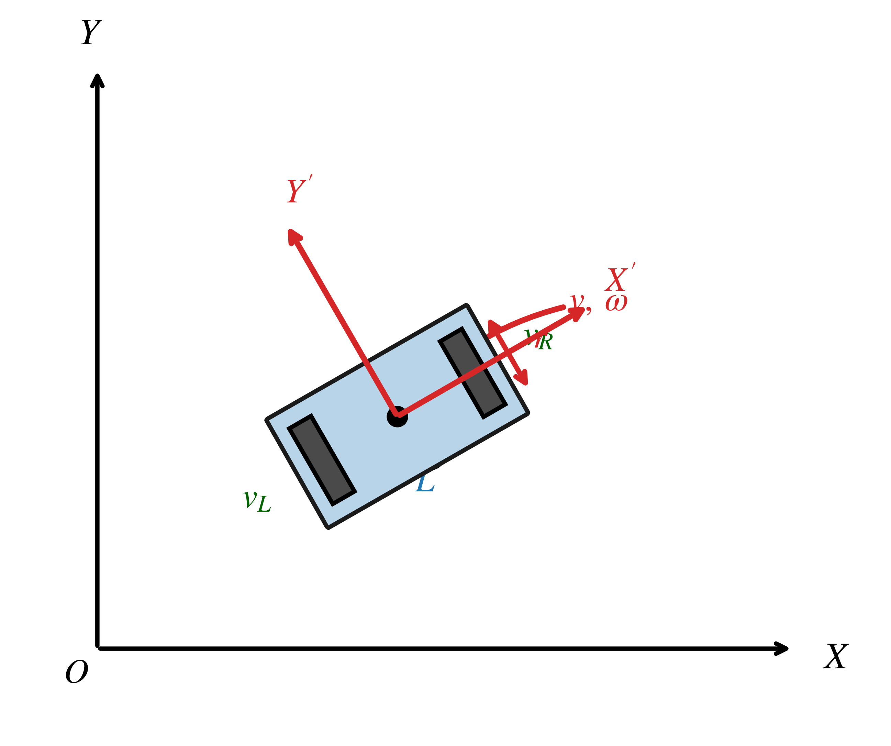
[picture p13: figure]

图 5-1 双轮差速移动机器人模型示意图

设机器人在二维平面内运动，定义全局坐标系 O− XY 和机器人坐标系 O

′ − X

′Y

′，其

中 O

′ 为机器人质心位置。机器人具有两个驱动轮，分别为左轮和右轮，轮距为 L，轮半

径为 r。设左轮和右轮的线速度分别为 vL 和 vR，则机器人的线速度 v 和角速度 ω 可以表

示为：

v =

vR + vL
2

(5-1)

ω =

vR − vL

L

(5-2)

机器人在全局坐标系中的位置 (x, y) 和姿态 θ 的变化率可由以下运动学方程描述：

x˙ = v cos θ | (5-3)
y˙ = v sin θ | (5-4)
θ˙ = ω | (5-5)

为便于在 MATLAB 中直接以线速度和角速度形式构造典型轨迹，进一步引入轮角

速度作为执行层输入。由差速底盘几何关系可得右轮和左轮的角速度分别为：

ωR =

2v + ωL 2r | (5-6)

ωL =

2v − ωL
2r

(5-7)

上述关系式与式(5-3)至式(5-5)共同构成差速机器人典型轨迹仿真的基础，只需给定

不同的 v(t) 和 ω(t)，即可通过积分得到机器人在平面内的位姿变化，并分析轨迹长度、

位移、曲率及左右轮角速度变化规律。

### 5.1 典型运动轨迹仿真与分析

依据附录程序 | traj_sim.m，在 MATLAB 环境下构建了差速机器人典型轨迹

运动学正解仿真模型。该仿真不涉及控制器，而是直接给定线速度指令 v(t) 和角速度指

令 ω(t)，通过前向欧拉积分方法对式(5-3)至式(5-5)进行离散求解，获得机器人在平面内

的位姿变化。仿真参数为：机器人初始位姿设为 (0, 0, 0)，轮半径取 r = 0.09 m，轮距取

L = 0.52 m，积分步长为 0.01 s，总仿真时间为 20 s。在此基础上，通过构造不同的速度

指令组合，分别得到直线轨迹、定曲率圆轨迹、S 形轨迹和 8 字轨迹四类典型运动形式，

用以分析差速底盘在不同工况下的轨迹特征和轮速变化规律。

5.1.1 直线运动

直线运动是最基本的运动形式，其控制输入设定为恒定线速度 v = 0.45 m/s、角速

度 ω = 0。其运动轨迹如图5-2所示。

图 5-2 直线运动轨迹仿真结果

由仿真结果可知，机器人沿 x 轴正方向做匀速直线运动，20 s 内累计路径长度约为

9.0 m，末端位移同样为 9.0 m，终点航向角保持为 0

◦。左右轮角速度始终相等，表明此

时差速底盘处于标准直行状态。

5.1.2 圆弧运动

圆弧运动对应仓储小车常见的连续转向工况。程序中设置 v = 0.35 m/s、ω =

0.45 rad/s，即线速度和角速度均保持常值，由此形成定曲率圆轨迹。其运动轨迹如图5-3所

示。

图 5-3 圆弧运动轨迹仿真结果

仿真结果表明，机器人在 20 s 内完成长度约为 7.0 m 的圆弧路径，终点位移约为

1.521 m，终点航向角约为 155.662◦。由于 ω/v 保持常数，轨迹曲率稳定不变，左右轮角

速度始终存在固定差值，体现了差速驱动借助恒定速差实现平滑转弯的特点。

5.1.3 S 形运动

S 形运动用来反映机器人在左右交替转向场景下的运动状态。程序中给定恒定线速

度 v = 0.40 m/s，并令角速度满足 ω(t) = 0.6 sin(0.5t)，使机器人在前进过程中周期性改变

转向方向。其运动轨迹如图5-4所示。

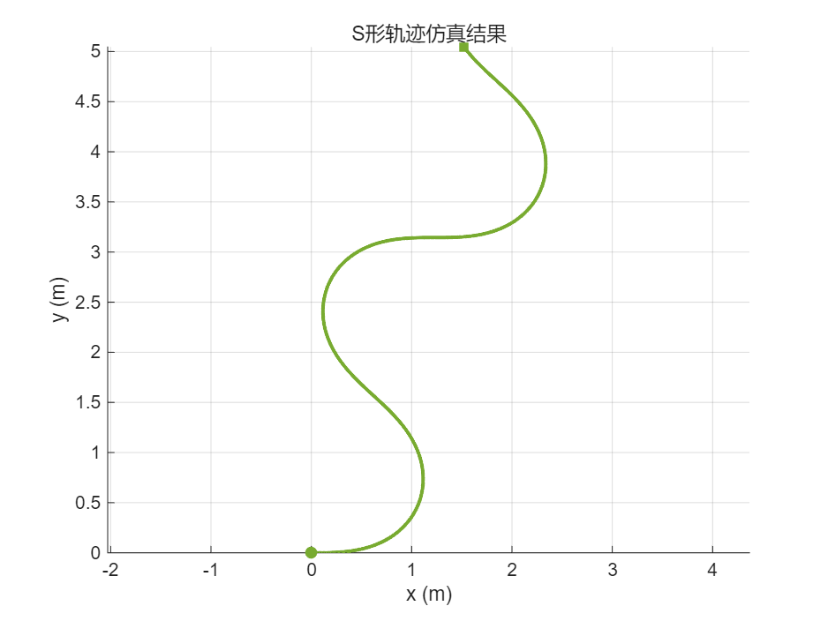
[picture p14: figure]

图 5-4 S 形运动轨迹仿真结果

仿真结果显示，该轨迹总路径长度约为 8.0 m，终点位移约为 5.269 m，最大角速度

达到 0.6 rad/s，最大曲率约为 1.5 m⁻¹。从轨迹形态来看，机器人在整体前进的同时完成

了多次连续换向，较好地体现了差速底盘在曲折通道中的灵活性。

5.1.4 8 字形运动

8 字形运动进一步增加了转向频率和曲率变化幅值。程序中设置线速度 v = 0.38 m/s，

角速度为 ω(t) = 0.7 sin(0.7t)，由此形成具有明显自交特征的 8 字形轨迹。其运动轨迹如

图5-5所示。

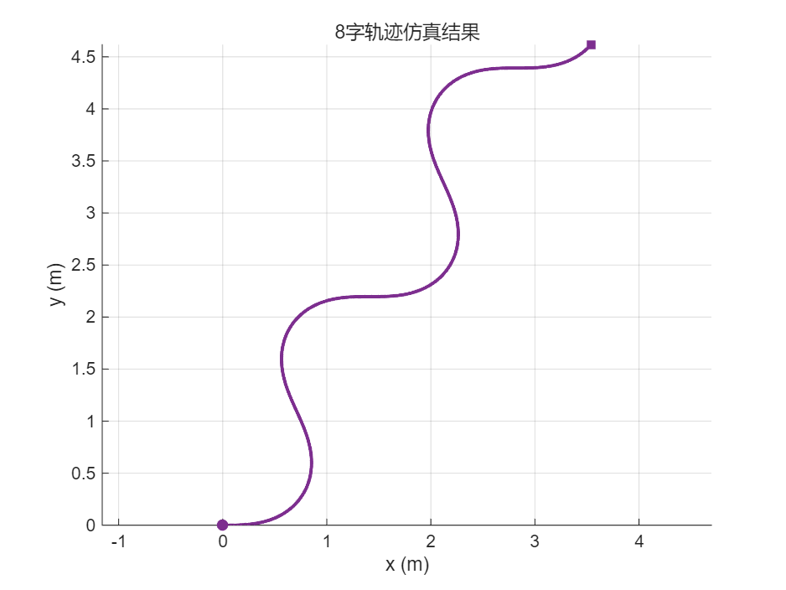
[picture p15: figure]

图 5-5 8 字形运动轨迹仿真结果

从结果可以看出，8 字轨迹总路径长度约为 7.6 m，终点位移约为 5.817 m，最大角

速度达到 0.7 rad/s，最大曲率约为 1.842 m⁻¹。与 S 形轨迹相比，该工况对机器人姿态变

化速度和轮速协调能力的要求更高，更适合用于验证差速底盘在复杂曲线路径下的运动

学响应特性。

四类轨迹的线速度指令如图5-6所示，直线轨迹为恒定值，S 形和 8 字轨迹因角速度

变化导致有效线速度波动。

图 5-6 四类轨迹线速度指令

角速度指令如图5-7所示，8 字轨迹的角速度幅值最大，达到 0.7 rad/s，对差速执行

机构的动态调节能力要求最高。

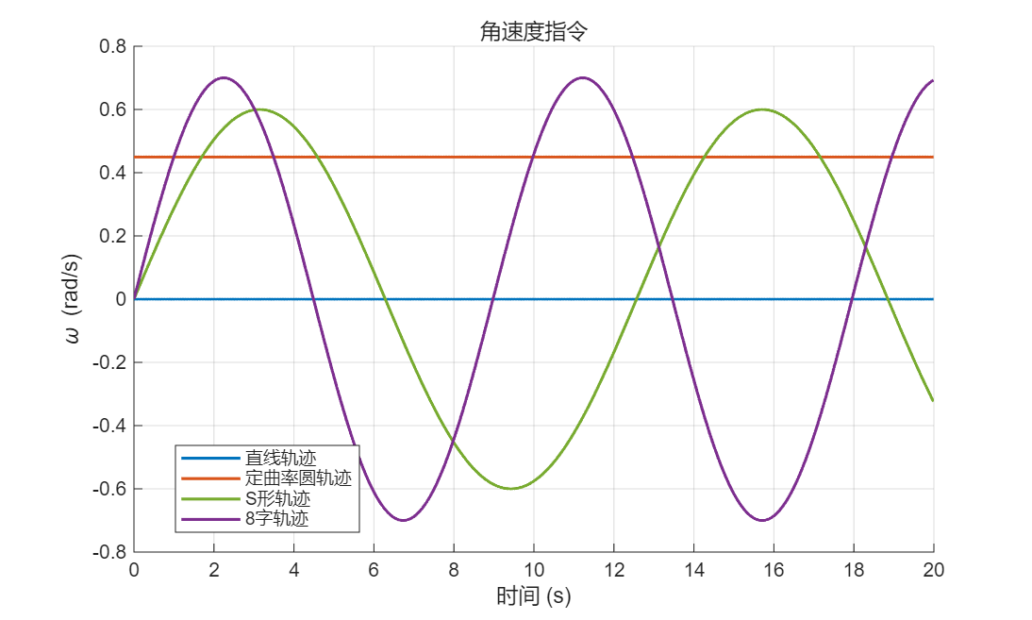
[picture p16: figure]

图 5-7 四类轨迹角速度指令

左右轮角速度如图5-8所示，直线轨迹下左右轮角速度完全重合，定曲率圆轨迹下两

轮保持恒定差值，S 形和 8 字轨迹下均呈周期性变化，且 8 字轨迹的轮速波动幅值更大。

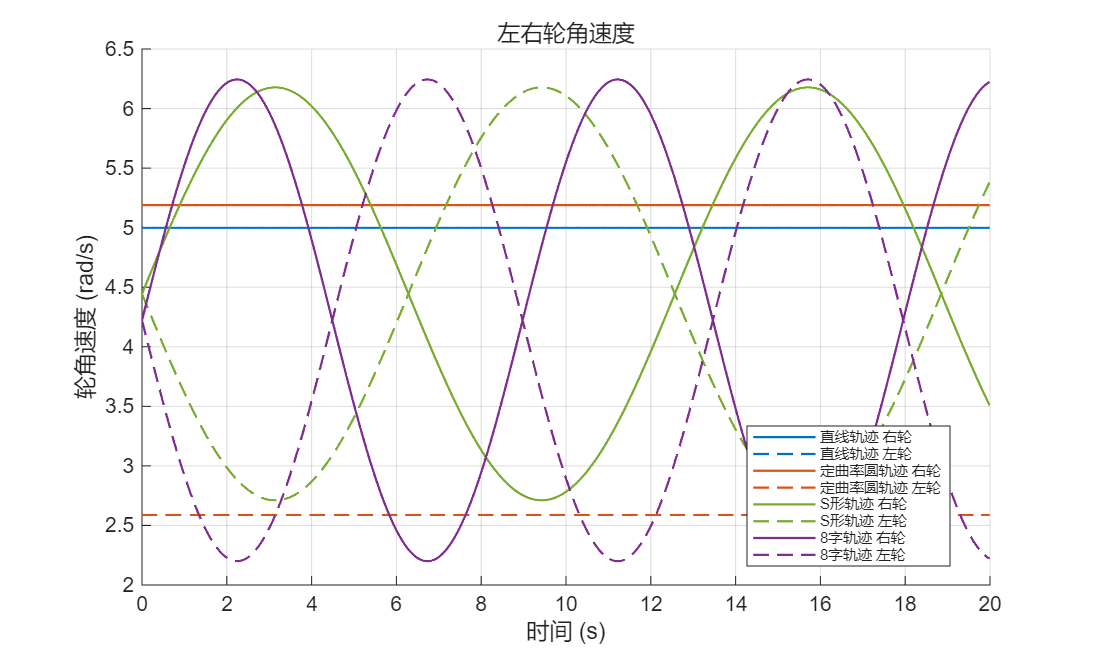
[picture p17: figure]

图 5-8 四类轨迹左右轮角速度

从左右轮角速度的变化规律可以进一步分析各轨迹的运动学特性。直线轨迹下，左

右轮角速度始终相等，差速底盘处于标准直行状态；定曲率圆轨迹下，两轮保持恒定的

角速度差值，对应恒定的转弯半径；S 形轨迹和 8 字轨迹下，轮速差呈周期性正弦变化，

且 8 字轨迹的波动幅值更大，表明其对差速执行机构的动态调节能力要求更高。

各类轨迹的瞬时曲率对比如图5-9所示。曲率反映了轨迹的弯曲程度，可由 κ = ω/v

计算得到。直线轨迹曲率始终为 0，定曲率圆轨迹曲率保持常值 1.286 m⁻¹，而 S 形轨迹

和 8 字轨迹的曲率均呈正负交替变化，其中 8 字轨迹的峰值达到 1.842 m⁻¹，表明其路径

弯曲程度最高，对底盘的转向响应能力要求最为严苛。

图 5-9 曲率对比图

为了更直观地对比不同轨迹的运动学特征，将仿真结果汇总如表5-1所示。由表可

见，四类轨迹在路径长度、平均速度和最大曲率等方面存在明显差异，其中 8 字轨迹的

最大角速度和最大曲率均为最大，是验证差速底盘综合运动性能的典型工况。

表 5-1 典型轨迹仿真结果汇总
轨迹类型 | 路径长 度/m | 位移/m | 平均速 度/(m/s) | 最大角速 度/(rad/s) | 最大曲 率/(m⁻¹
)
直线轨迹 | 9.0 | 9.0 | 0.45 | 0 | 0
定曲率圆轨 迹 | 7.0 | 1.521 | 0.35 | 0.45 | 1.286
S 形轨迹 | 8.0 | 5.269 | 0.40 | 0.60 | 1.500
8 字轨迹 | 7.6 | 5.817 | 0.38 | 0.70 | 1.842

以上仿真结果显示，基于 traj_sim.m 的差速机器人运动学仿真能够反映不同速度

指令组合下的轨迹变化规律：直线轨迹体现了底盘的基础直行能力，定曲率圆轨迹反

映了稳态转弯特性，S 形和 8 字轨迹则呈现了机器人在连续变曲率工况下的姿态调整能

力。
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

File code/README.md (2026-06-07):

# 智能仓储自主移动机器人结构设计与控制

> **齐鲁工业大学 · 机械工程学院 · 2026届本科毕业论文（设计）**
>
> 答辩人：王子煜 ｜ 指导教师：刘鹏博 ｜ 学号：202201230042

---

## 项目简介

针对中小型仓储场景中物料搬运自动化程度不足的问题，**从零设计了一款集成剪叉式举升功能的双轮差速驱动移动机器人**。项目覆盖了产品开发的完整技术链条——从需求分析、方案论证、机械结构设计、电气系统选型，到运动学建模、路径规划算法、PID控制仿真验证，最终形成一套可落地的工程方案。

**一句话概括**：让一台 200 kg 的小车，载着 50 kg 货物，在货架间自主导航、精准停靠、平稳升降。

---

## 系统架构

```
┌─────────────────────────────────────────────────────┐
│                   决策层（离线）                       │
│   Hybrid A* 全局路径规划 → 5种曲率 × 2方向 = 10基元    │
│   10m×8m 仓储地图 · 5个货架障碍物 · 路径 11.04 m       │
└──────────────────────────┬──────────────────────────┘
                           │ 参考路径
┌──────────────────────────▼──────────────────────────┐
│                   执行层（在线 · 5 ms 周期）            │
│   5路TCRT5000红外传感器 → 加权偏移 → PID纠偏            │
│   RMS 横向误差 1.5 cm · 最大误差 6.8 cm               │
└──────────────────────────┬──────────────────────────┘
                           │ ω_cmd
┌──────────────────────────▼──────────────────────────┐
│                   控制层（双环PID级联）                 │
│   外环·位姿环（PID） → 内环·轮速环（PI）                │
│   位姿环: Kp=3.0/Ki=0.2/Kd=0.4                       │
│   轮速环: Kp=17.0/Ki=103.0 · 抗积分饱和               │
└──────────────────────────┬──────────────────────────┘
                           │ PWM
┌──────────────────────────▼──────────────────────────┐
│                   驱动层（硬件）                       │
│   SMC80S 伺服电机(400W) × ZJPX115 行星减速器(40:1)     │
│   STM32F103C8T6 主控 · 编码器 10000脉冲/转             │
│   TCRT5000红外 ×5 · HC-SR04超声波 · 2500P/R编码器     │
└─────────────────────────────────────────────────────┘
```

---

## 核心指标一览

<div align="center">

| 🏗️ 结构强度 | 🎯 控制精度 | 🗺️ 路径规划 |
|:---:|:---:|:---:|
| 臂杆应力 **5.56 MPa** | 定点误差 **2.2 cm** | 路径长度 **11.04 m** |
| 许用应力 156.7 MPa | 航向误差 **< 1°** | 搜索迭代 3134 次 |
| 安全裕度 **96.5%** | 线速度 RMSE **0.0086 m/s** | 满足运动学约束 |
| 屈曲安全系数 **10.1** | 循迹 RMS **1.5 cm** | 无需后处理平滑 |

</div>

---
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

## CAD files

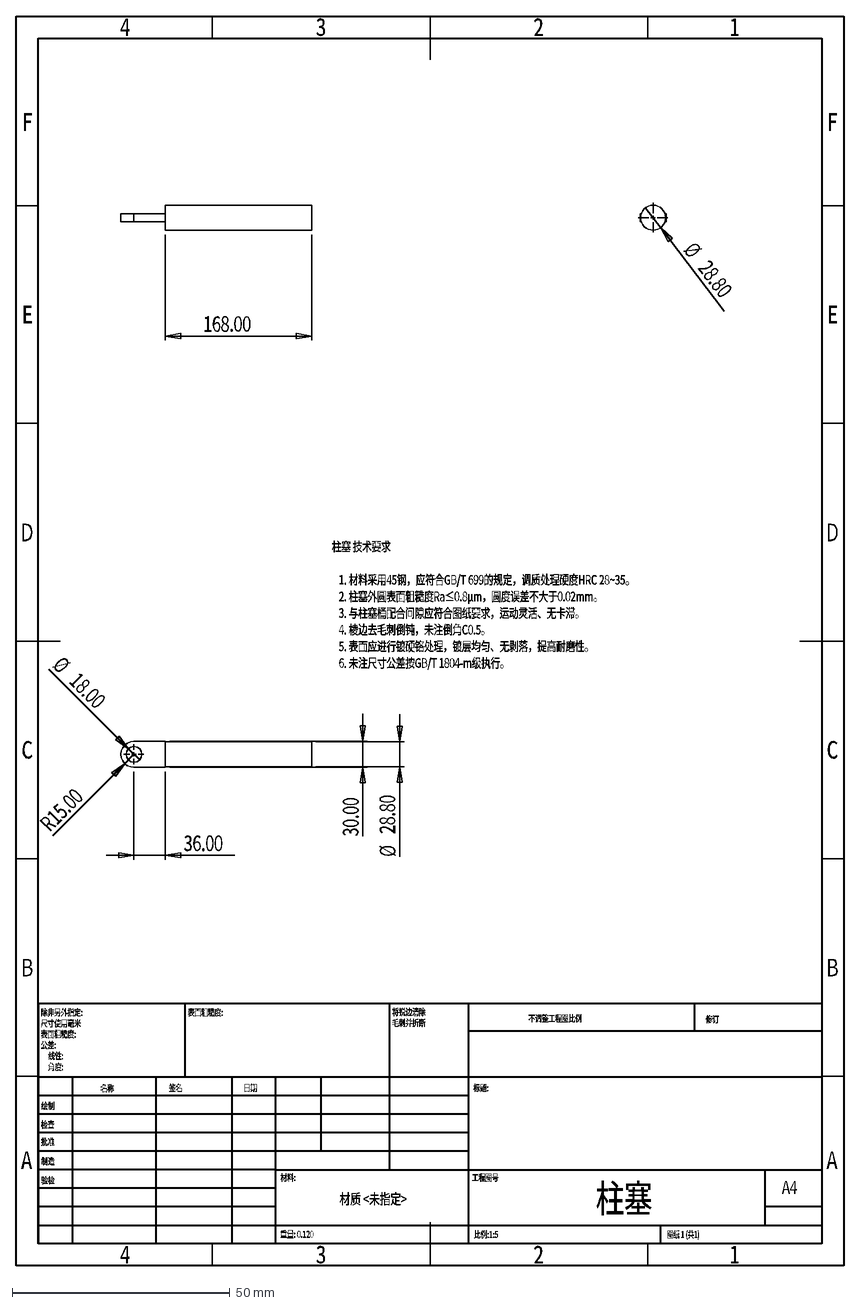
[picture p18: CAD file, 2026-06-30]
sw/07/柱塞.dxf
柱塞 技术要求
1. 材料采用45钢，应符合GB/T 699的规定，调质处理硬度HRC 28~35。
2. 柱塞外圆表面粗糙度Ra≤0.8μm，圆度误差不大于0.02mm。
3. 与柱塞桶配合间隙应符合图纸要求，运动灵活、无卡滞。
4. 棱边去毛刺倒钝，未注倒角C0.5。
5. 表面应进行镀硬铬处理，镀层均匀、无剥落，提高耐磨性。
6. 未注尺寸公差按GB/T 1804-m级执行。
A
B
C
D
E
F
4
3
2
1
绘制
检查
批准
制造
验检
除非另外指定:
尺寸使用毫米
表面粗糙度:
公差:
线性:
角度:
将锐边清除
毛刺并折断
名称
签名
日期
材料:
不调整工程图比例
修订
标题:
工程图号
比例:1:5
图纸 1 (共1)
A4
材质 <未指定>
重量: 0.120
柱塞
168.00
36.00
R15.00
Ø
18.00
30.00
28.80

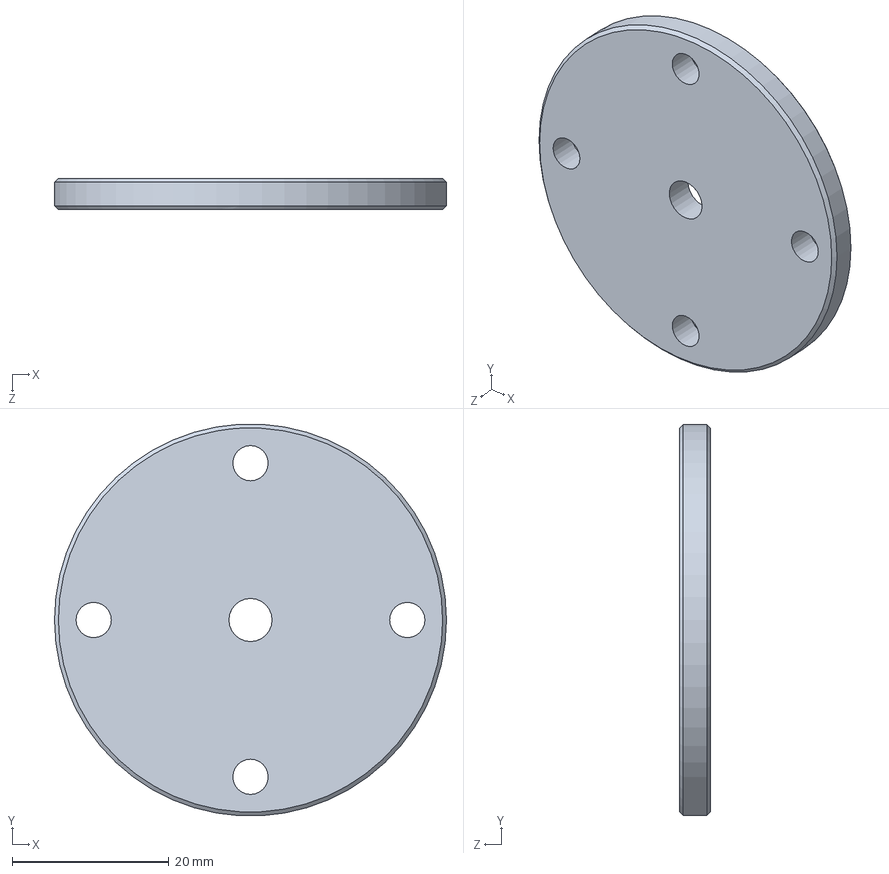
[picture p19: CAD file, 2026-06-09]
sw/agv小车/驱动轮端盖.SLDPRT
50.0 x 49.9 x 4.00 mm

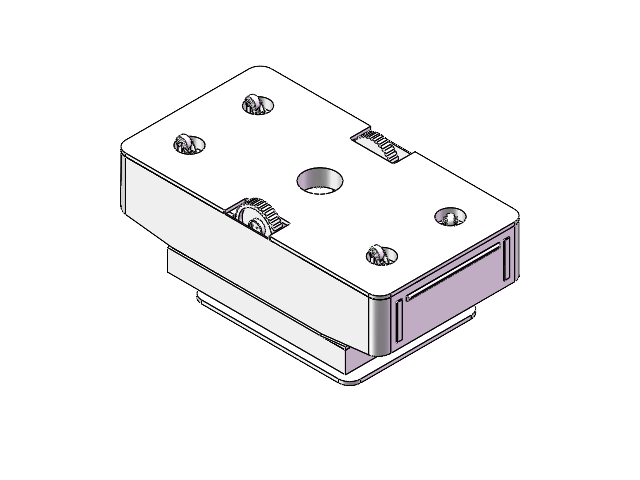
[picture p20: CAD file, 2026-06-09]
sw/小车结构总装.SLDASM
agv小车结构设计WANXIANGLUNHUIZHUANZUO x 4
agv小车结构设计WANXIANGLUNJIA x 4
agv小车结构设计WANXIANGLUN x 4
agv小车结构设计WANXIANGLUNZHOU x 4
agv小车结构设计底板
agv小车结构设计JIANSUJI
agv小车结构设计QUDONGDIANJIZUO
agv小车结构设计XUANZHUANBIANMAQIGUOCHAN
agv小车结构设计QUDONGLUN
agv小车结构设计QUDONGLUNDUANGAI
agv小车结构设计DIANJIZHIJIA
agv小车结构设计QUDONGLUNTANHUANG
镜向agv小车结构设计JIANSUJI
镜向agv小车结构设计QUDONGDIANJIZUO
镜向agv小车结构设计XUANZHUANBIANMAQIGUOCHAN
镜向agv小车结构设计QUDONGLUN
镜向agv小车结构设计QUDONGLUNDUANGAI
镜向agv小车结构设计DIANJIZHIJIA
镜向agv小车结构设计QUDONGLUNTANHUANG
agv小车结构设计GUANGZHOU20TANHUANG
镜向2021二维码agv小车结构设计GUANGZHOU20TANHUANG
AGV罩壳
警示灯 x 2
cross recessed pan head screws gb x 4
传感器
底座
固定支架
滑块 x 4
滑动支架
柱塞
柱塞桶
台面
固定轮 x 2
零件1 x 2
零件2
支撑1
支撑1 - 副本
hex flange bolts-heavy grade b gb x 4
tuban

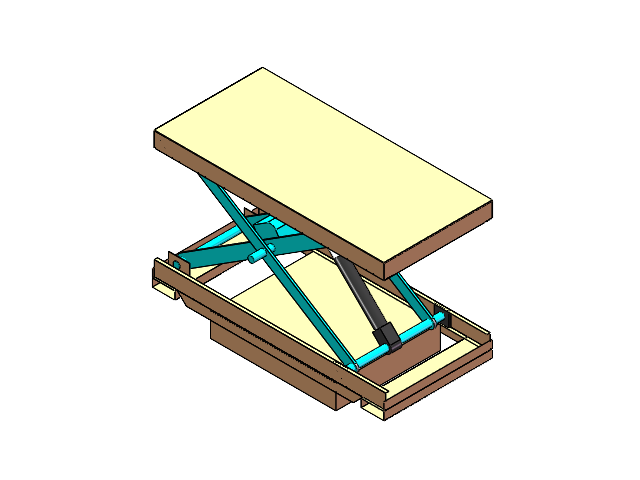
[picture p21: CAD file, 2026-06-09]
sw/agv小车/升降机11.SLDASM
底座
固定支架
滑块 x 4
滑动支架
柱塞
柱塞桶
台面
固定轮 x 2
零件1

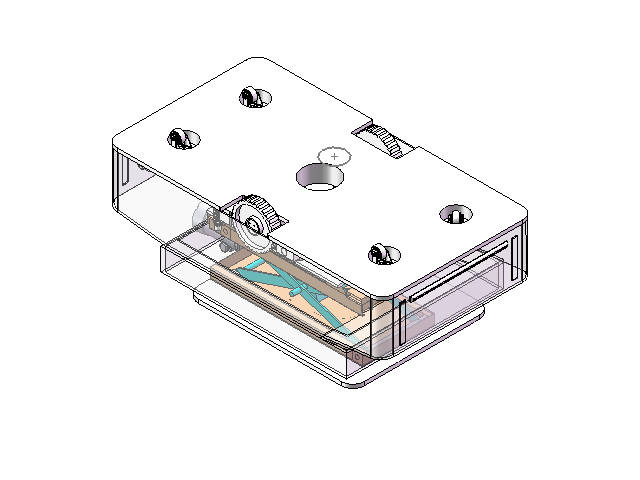
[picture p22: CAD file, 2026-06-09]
sw/agv小车/agv小车结构总装.SLDASM
agv小车结构设计WANXIANGLUNHUIZHUANZUO x 4
agv小车结构设计WANXIANGLUNJIA x 4
agv小车结构设计WANXIANGLUN x 4
agv小车结构设计WANXIANGLUNZHOU x 4
agv小车结构设计底板
agv小车结构设计JIANSUJI
agv小车结构设计QUDONGDIANJIZUO
agv小车结构设计XUANZHUANBIANMAQIGUOCHAN
agv小车结构设计QUDONGLUN
agv小车结构设计QUDONGLUNDUANGAI
agv小车结构设计DIANJIZHIJIA
agv小车结构设计QUDONGLUNTANHUANG
镜向agv小车结构设计JIANSUJI x 2
镜向agv小车结构设计QUDONGDIANJIZUO x 2
镜向agv小车结构设计XUANZHUANBIANMAQIGUOCHAN
镜向agv小车结构设计QUDONGLUN
镜向agv小车结构设计QUDONGLUNDUANGAI
镜向agv小车结构设计DIANJIZHIJIA
镜向agv小车结构设计QUDONGLUNTANHUANG
agv小车结构设计GUANGZHOU20TANHUANG
镜向2021二维码agv小车结构设计GUANGZHOU20TANHUANG
AGV罩壳
支架
警示灯 x 2
零件1^agv小车结构总装
cross recessed cheese head screws gb x 4
cross recessed pan head screws gb x 4
agv小车结构设计TUOBAN
传感器
底座
固定支架
滑块 x 4
滑动支架
柱塞
柱塞桶
台面
固定轮 x 2
零件2^agv小车结构总装

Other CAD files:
sw/agv小车/agv小车结构设计QUDONGLUNZUZHUANG_ASM.SLDASM
sw/agv小车/零件5_QC_00000 ASM.SLDPRT
sw/agv小车/agv小车结构设计WANXIANGLUNZUZHUANG_AF1_ASM.SLDASM
sw/agv小车/3222.SLDASM
sw/agv小车/零件10_QC_00000 ASM.SLDPRT
sw/agv小车/agv小车结构设计DIPAN_ASM.SLDASM
sw/agv小车/agv小车结构设计WANXIANGLUNZUZHUANG_AF2_ASM.SLDASM
sw/agv小车/镜向2021二维码agv小车结构设计QUDONGLUNZUZHUANG_ASM.SLDASM
sw/agv小车/agv小车结构设计HUIZHUANDIANJIZUZHUANG_ASM.SLDASM
sw/agv小车/agv小车结构设计WANXIANGLUNZUZHUANG_AF0_ASM.SLDASM
sw/agv小车/agv小车结构设计WANXIANGLUNZUZHUANG_AF3_ASM.SLDASM
sw/agv小车/agv小车结构设计SHENGJIANGBUFENZUZHUANG_ASM.SLDASM
sw/二维图/柱塞桶.DWG
sw/07/万向轮.dxf
sw/07/万向轮回转座.dxf
sw/07/万向轮支架.dxf
sw/07/万向轮轴.dxf
sw/07/固定轮.dxf
sw/07/小车结构总装.dxf
sw/07/弹簧.dxf
sw/07/柱塞桶.dxf
sw/07/滑动支架.dxf
sw/07/滑块.dxf
sw/07/电机支架.dxf
sw/07/载物台.dxf
sw/07/驱动轮.dxf
sw/07/驱动轮端盖.dxf
sw/agv小车/111111111.SLDASM
sw/agv小车/AGV罩壳.SLDPRT
sw/agv小车/agv小车结构设计DIANJIZHIJIA.SLDPRT
sw/agv小车/agv小车结构设计GUANGZHOU20TANHUANG.SLDPRT
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

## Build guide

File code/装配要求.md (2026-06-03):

# 智能仓储举升式AGV小车装配要求

## 一、总则

1. 所有零部件装配前须检验合格，去毛刺、锐边倒钝，清洗干净后方可装配。
2. 装配环境应保持清洁，无铁屑、灰尘等杂物混入运动副。
3. 所有紧固件拧紧力矩应符合设计要求，关键连接处须采取防松措施（弹簧垫圈、防松螺母或螺纹锁固胶）。
4. 装配过程中不得损伤零件表面，严禁强行敲击配合面。

---

## 二、底盘装配要求

1. 底盘框架焊缝应均匀、饱满，无裂纹、气孔、夹渣等缺陷，焊后清除焊渣并打磨平整。
2. 承载平台板（660 mm × 312 mm × 3 mm，Q235钢板）平面度公差不大于1 mm。
3. 两驱动轮安装孔中心距为520 mm ± 0.5 mm，同轴度公差不大于Φ0.1 mm。
4. 两万向轮安装位置应保证与驱动轮形成的支撑面共面，四轮同时着地，任意三点确定的平面内第四点翘起量不大于1 mm。
5. 驱动轮安装支架与底盘连接螺栓强度等级不低于8.8级，拧紧力矩按设计要求执行。

---

## 三、驱动轮总成装配要求

1. 伺服电机（SMC80S-0040-30AoK-3DKH，400W）与行星减速器（ZJPX115，速比40:1）连接前，须确认电机输出轴与减速器输入轴的同轴度，径向跳动不大于0.05 mm。
2. 减速器输出法兰与驱动轮轴的连接应可靠，键配合间隙符合H7/h6过渡配合要求。
3. 驱动轮（聚氨酯橡胶轮，Φ180 mm）安装后径向跳动不大于0.5 mm，端面跳动不大于0.3 mm。
4. 电机动力线与编码器信号线应分开走线，信号线须采用屏蔽线，屏蔽层单端接地。
5. 两驱动轮安装完成后，轮面对称中心面应与小车纵向中心面平行，平行度公差不大于0.5 mm。

---

## 四、万向轮装配要求

1. 万向轮安装位置应保证小车满载（50 kg额定载荷）时转动灵活，无卡滞现象。
2. 万向轮支架与底盘连接牢固，连接螺栓须加弹簧垫圈防松。
3. 万向轮底部与地面接触后，轮架应能360°自由旋转，旋转阻力矩不大于0.3 N·m。

---

## 五、剪叉式升降机构装配要求

### 5.1 剪叉臂杆装配

1. 剪叉臂杆（Q235扁钢，截面36 mm × 4.8 mm，孔心距600 mm）两根为一组，交叉布置，交叉中心铰接。
2. 臂杆两端铰孔同轴度公差不大于Φ0.05 mm，孔径公差为H7。
3. 两根臂杆交叉中心铰接后，应保证运动灵活，无明显松旷，铰接间隙不大于0.05 mm。
4. 臂杆表面应涂防锈底漆，涂层均匀、无流挂。

### 5.2 中心铰轴装配

1. 中心铰轴（Φ18 mm，45#钢，调质处理）与臂杆铰孔配合为H7/f6间隙配合。
2. 铰轴安装后轴向定位可靠，采用轴用弹性挡圈或轴端挡板固定，防止轴向窜动。
3. 铰轴表面粗糙度Ra不大于1.6 μm，硬度HRC 28～35。

### 5.3 底部固定铰座与滑动导轨装配

1. 底部固定铰座与底盘连接应牢固，铰座销孔中心线与底盘上平面平行度公差不大于0.2 mm。
2. 底部滑动导轨安装直线度公差不大于0.3 mm/m，导轨面与底盘上平面平行度公差不大于0.2 mm。
3. 滑块在导轨上运动应平稳、无卡滞，全程滑动顺畅。滑块与导轨间隙通过调整垫片控制在0.02～0.08 mm。

### 5.4 顶部铰座与滚轮机构装配

1. 顶部固定铰座与承载平台连接牢固，销孔中心线与平台底面平行度公差不大于0.2 mm。
2. 顶部滚轮应转动灵活，滚轮与接触面之间为滚动摩擦，不得出现滑动摩擦或卡死现象。
3. 滚轮轴向定位可靠，径向跳动不大于0.1 mm。

### 5.5 电动推杆装配

1. 电动推杆安装位置应准确，推杆轴线与滑块运动方向一致，同轴度公差不大于Φ0.5 mm。
2. 推杆两端铰接应灵活，连接销轴防松可靠。
3. 推杆伸缩全程应平稳，无爬行、抖动现象，最大伸缩力满足升降载荷要求。

### 5.6 升降机构整体要求

1. 升降机构装配完成后，手动推动升降应轻便灵活，无卡滞、异响。
2. 空载状态下，平台最低高度149 mm ± 5 mm，最高高度600 mm ± 5 mm，行程约452 mm。
3. 额定载荷50 kg状态下，平台升降平稳，四角高度差不大于2 mm。
4. 载荷偏心（偏心距不大于平台短边1/4）时，升降机构不得出现卡死或明显倾斜。

---

## 六、承载平台装配要求

1. 承载平台板（660 mm × 312 mm × 3 mm，Q235钢板）与升降机构顶部铰座/滚轮机构连接可靠。
2. 平台板上表面平面度公差不大于1 mm，表面无明显凹凸变形。
3. 平台板四边应倒角去毛刺，棱边倒角C1～C2。

---

## 七、传感器安装要求

1. 5只TCRT5000红外循迹传感器安装在驱动轮轴前方80 mm处，相邻传感器间距40 mm，总覆盖宽度160 mm。
2. 传感器安装底面距地面检测距离1～25 mm，安装支架刚度足够，工作时不得产生明显振动。
3. HC-SR04超声波避障传感器安装在小车前端，探头朝向正前方，安装高度与障碍物检测需求匹配。
4. 传感器接线应牢固，走线整齐，采用扎带固定，不得与运动部件干涉。

---

## 八、电气系统装配要求

1. 控制板（STM32F103C8T6）安装位置应远离电机和减速器等强振动源，固定牢靠。
2. 动力线与信号线分开布线，间距不小于50 mm；交叉时应90°交叉。
3. 所有接线端子压接牢固，不得虚接；接插件应有锁紧或卡扣防脱结构。
4. 线束应采用波纹管或线槽保护，在经过棱角处加橡胶护套防磨损。
5. 整车电气系统应可靠接地，接地电阻不大于0.1 Ω。

---

## 九、整机装配与调试要求

1. 整机装配完成后，检查所有紧固件拧紧状态，关键螺栓须做拧紧标记。
2. 空载试运行：小车前进、后退、左转、右转各方向运行不少于5 min，运行平稳，无异常噪声和振动。
3. 升降试运行：空载升降不少于10个全程循环，机构运动灵活、平稳。
4. 额定载荷试验：承载50 kg额定载荷，重复上述行走和升降试验，各项指标满足设计要求。
5. 循迹精度测试：在标准循迹线上运行，偏差不大于±10 mm。
6. 避障功能测试：前方400 mm内有障碍物时，小车应能可靠检测并制动。
7. 整机噪声：额定工况下运行噪声不大于65 dB(A)。

---

## 十、涂装与外观要求

1. 所有金属结构件非配合表面涂底漆一道、面漆一道，漆膜总厚度不小于60 μm。
2. 漆面应均匀、平整，无流挂、起泡、剥落、露底等缺陷。
3. 外露螺栓头、螺母等紧固件涂防锈油或做镀锌处理。
4. 整机外观整洁，各零部件装配位置正确，无遗漏件。

---

## 十一、验收与标记

1. 装配完成后，应进行整机检验，填写装配检验记录。
2. 合格产品应加贴铭牌，标明产品名称、型号、额定载荷、最大速度、出厂编号、出厂日期等信息。
3. 随机附带产品使用说明书、装箱清单、合格证及必要的备件。

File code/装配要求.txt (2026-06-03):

1. 所有零件装配前须去毛刺、清洗干净，运动副处涂润滑脂。
2. 紧固件拧紧力矩按设计要求，关键连接处加弹簧垫圈防松。
3. 两驱动轮中心距520±0.5mm，轮面对称中心面与车体纵向中心面平行度不大于0.5mm。
4. 剪叉臂杆铰接处配合间隙不大于0.05mm，升降全程运动灵活、无卡滞。
5. 底部导轨直线度不大于0.3mm/m，滑块与导轨间隙0.02~0.08mm。
6. 整机装配后空载试运行，行走平稳无异响，升降10个循环无卡滞，额定载荷50kg下平台四角高度差不大于2mm。

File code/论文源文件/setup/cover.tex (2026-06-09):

% !Mode:: "TeX:UTF-8"

%? ************************************************************* %?
%?                                                               %?
%?                   您将在此处完成封面个人信息填写                   %?
%?                                                               %?
%? ************************************************************* %?

\cheading{齐鲁工业大学~2026~届本科毕业论文（设计）}   % 设置正文的页眉，需要填上对应的毕业年份
\thtitle{智能仓储自主移动机器人结构设计与控制}               % 论文题目 
\caffil{\heiti\sihao{机械工程学院}}          % 学部/院名称
\csubject{\heiti\sihao{机器人（SI）22-2}}                % 专业班级
\cauthor{\heiti\sihao{王子煜}}                   % 学生姓名
\cnumber{\heiti\sihao{202201230042}}           % 学生学号
\csupervisor{\heiti\sihao{刘鹏博\quad 王月光}}      % 导师姓名
\cdate{2026~~年~~03~~月~~10~~日}                 % 日期

% \cdate{\the\year~年~\the\month~月~\the\day~日} % AutoTime

\makecover
\clearpage
\makesubcover
\clearpage

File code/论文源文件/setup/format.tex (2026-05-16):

% !Mode:: "TeX:UTF-8"

%*  Authors: 张井   Jing Zhang: prayever@gmail.com     天津大学2010级管理与经济学部信息管理与信息系统专业硕士生
%*           余蓝涛 Lantao Yu: lantaoyu1991@gmail.com  天津大学2008级精密仪器与光电子工程学院测控技术与仪器专业本科
%*           李赟博 齐鲁工业大学 2019级数学与人工智能学院智能科学与技术专业本科
%*           XLY23333 齐鲁工业大学 2022级数学与人工智能学部智能科学与技术专业本科

%! ************************************************************* %!
%!              _       __                 _                     %!
%!             | |     / /___ __________  (_)___  ____ _         %!
%!             | | /| / / __ `/ ___/ __ \/ / __ \/ __ `/         %!
%!             | |/ |/ / /_/ / /  / / / / / / / / /_/ /          %!
%!             |__/|__/\__,_/_/  /_/ /_/_/_/ /_/\__, /           %!
%!                                             /____/            %!
%!          如果您不知道如何修改LaTeX,请勿随意尝试修改本文件!           %!
%! ************************************************************* %!

%%%%%%%%%%%%%%%%% Fonts Definition and Basics %%%%%%%%%%%%%%%%%
% Import Font
% SimSun
\setCJKfamilyfont{simsun}{simsun}[Path=static/font/,Extension=.ttf, BoldFont=simsunbold.ttf]
\renewcommand{\songti}{\CJKfamily{simsun}}
% SimHei
\setCJKfamilyfont{simhei}{simhei}[Path=static/font/,Extension=.ttf, BoldFont=simheibold.ttf]
\renewcommand{\heiti}{\CJKfamily{simhei}}
% SimFangSong
\setCJKfamilyfont{simfang}{simfang}[Path=static/font/,Extension=.ttf]
\renewcommand{\fangsong}{\CJKfamily{simfang}}
% Set Font Size
\newcommand{\maintitle}{\fontsize{36pt}{36pt}}                % 小初, 单倍行距
\newcommand{\yihao}{\fontsize{26pt}{26pt}\selectfont}       % 一号, 单倍行距
\newcommand{\xiaoyi}{\fontsize{24pt}{24pt}\selectfont}      % 小一, 单倍行距
\newcommand{\erhao}{\fontsize{22pt}{1.25\baselineskip}\selectfont}       % 二号, 1.25倍行距
\newcommand{\xiaoer}{\fontsize{18pt}{18pt}\selectfont}      % 小二, 单倍行距
\newcommand{\sanhao}{\fontsize{16pt}{16pt}\selectfont}      % 三号, 单倍行距
\newcommand{\xiaosan}{\fontsize{15pt}{15pt}\selectfont}     % 小三, 单倍行距
\newcommand{\sihao}{\fontsize{14pt}{14pt}\selectfont}       % 四号, 单倍行距
\newcommand{\xiaosi}{\fontsize{12pt}{12pt}\selectfont}      % 小四, 单倍行距
\newcommand{\wuhao}{\fontsize{10.5pt}{10.5pt}\selectfont}   % 五号, 单倍行距
\newcommand{\xiaowu}{\fontsize{9pt}{9pt}\selectfont}        % 小五, 单倍行距
% XFont Style (人工测量行距)
\newcommand{\xfsm}{\songti\xiaosi\setstretch{1.63}}           % Xfont声明文本   
\newcommand{\xfbody}{\songti\xiaosi\setstretch{1.95}}         % Xfont正文文本 
\newcommand{\xfabstract}{\fangsong\xiaosi\setstretch{1.95}}   % Xfont摘要文本 
\newcommand{\xfenabstract}{\fangsong\xiaosi\setstretch{1.73}} % XfontAbstract文本 

%\CJKtilde  % 重新定义了波浪符~的意义
% JUST DON'T USE CJK
% 使用 ctexbook 之后已无必要
\newcommand\prechaptername{第}
\newcommand\postchaptername{章}

\punctstyle{hangmobanjiao}             % 调整中文字符的表示，行内占一个字符宽度，行尾占半个字符宽度

% 调整罗列环境的布局
\setitemize{leftmargin=3em,itemsep=0em,partopsep=0em,parsep=0em,topsep=-0em}
\setenumerate{leftmargin=3em,itemsep=0em,partopsep=0em,parsep=0em,topsep=0em}

% 避免宏包 hyperref 和 arydshln 不兼容带来的目录链接失效的问题。
\def\temp{\relax}
\let\temp\addcontentsline
\gdef\addcontentsline{\phantomsection\temp}

% 自定义项目列表标签及格式 \begin{publist} 列表项 \end{publist}
\newcounter{pubctr} %自定义新计数器
\newenvironment{publist}{%%%%%定义新环境
\begin{list}{[\arabic{pubctr}]} %%标签格式
    {
     \usecounter{pubctr}
     \setlength{\leftmargin}{2.5em}   % 左边界 \leftmargin =\itemindent + \labelwidth + \labelsep
     \setlength{\itemindent}{0em}     % 标号缩进量
     \setlength{\labelsep}{1em}       % 标号和列表项之间的距离,默认0.5em
     \setlength{\rightmargin}{0em}    % 右边界
     \setlength{\topsep}{0ex}         % 列表到上下文的垂直距离
     \setlength{\parsep}{0ex}         % 段落间距
     \setlength{\itemsep}{0ex}        % 标签间距
     \setlength{\listparindent}{0pt}  % 段落缩进量
    }}
{\end{list}}

\makeatletter
\renewcommand\normalsize{
  \@setfontsize\normalsize{12pt}{12pt} % 小四对应 12 pt
  \setlength\abovedisplayskip{4pt}
  \setlength\abovedisplayshortskip{4pt}
  \setlength\belowdisplayskip{\abovedisplayskip}
  \setlength\belowdisplayshortskip{\abovedisplayshortskip}
  \let\@listi\@listI}
\def\defaultfont{\renewcommand{\baselinestretch}{1.63}\normalsize\songti\xiaosi\selectfont} % 设置行距

\renewcommand{\CJKglue}{\hskip -0.1 pt plus 0.08\baselineskip} % 控制字间距，使每行 34 个汉字
\makeatother

%%%%%%%%%%%%% Contents %%%%%%%%%%%%%%%%%
\renewcommand{\contentsname}{\heiti\sanhao\textbf{目\qquad 录}}%%%%%%%%%%%%%%%%%%%%%%%%%%%%%%%%%%%%%%%%%%%%%%%
\setcounter{tocdepth}{2} % 目录大小参数调整
\titlecontents{chapter}[0em]{\vspace{0.045\baselineskip}\xiaosan\heiti}
             {\thecontentslabel\ }{}
             {\hspace{.5em}\titlerule*[4pt]{$\cdot$}\sihao\contentspage}
\titlecontents{section}[1.9em]{\vspace{0.045\baselineskip}\sihao\heiti}
             {\thecontentslabel\ }{}
             {\hspace{.5em}\titlerule*[4pt]{$\cdot$}\sihao\contentspage}
\titlecontents{subsection}[3.5em]{\vspace{0.045\baselineskip}\sihao\heiti}
             {\thecontentslabel\ \ }{}
             {\hspace{.5em}\titlerule*[4pt]{$\cdot$}\sihao\contentspage}

%%%%%%%%%% Chapter and Section %%%%%%%%%%%%%
\setcounter{secnumdepth}{4}
\setlength{\parindent}{2em}
\renewcommand{\chaptername}{\prechaptername\CJKnumber{\thechapter}\postchaptername}
\titleformat{\chapter}{\centering\xiaosan\songti}{\heiti\chaptername}{2em}{}
\titlespacing{\chapter}{0pt}{0.1\baselineskip-10mm}{0\baselineskip}
\titleformat{\section}{\sihao\heiti}{\thesection}{0.4em}{}
\titlespacing{\section}{0pt}{0\baselineskip}{0\baselineskip}
\titleformat{\subsection}{\sihao\heiti}{\thesubsection}{0.5em}{}
\titlespacing{\subsection}{0pt}{0.8\baselineskip}{0.1\baselineskip}
\titleformat{\subsubsection}{\sihao\heiti}{\thesubsubsection}{1em}{}
\titlespacing{\subsubsection}{0pt}{0.5\baselineskip}{0.1\baselineskip}

%%%%%%%%%% Table, Figure, Code and Equation %%%%%%%%%%%%%%%%%
\renewcommand{\tablename}{表}                                     % 插表题头
\renewcommand{\figurename}{图}                                    % 插图题头
\renewcommand{\thefigure}{\arabic{chapter}-\arabic{figure}}       % 使图编号为 7-1 的格式 %\protect{~}
\renewcommand{\thesubfigure}{(\alph{subfigure})}                   % 使子图编号为 a) 的格式
\renewcommand{\thesubtable}{(\alph{subtable})}                    % 使子表编号为 (a) 的格式
\renewcommand{\thetable}{\arabic{chapter}-\arabic{table}}         % 使表编号为 7-1 的格式
\renewcommand{\theequation}{\arabic{chapter}-\arabic{equation}}   % 使公式编号为 7-1 的格式
\newcommand{\ud}{\mathrm{d}}
% 公式适配
\AtBeginEnvironment{equation}{\vspace{-2.5em}}  % 减少公式顶部空白
\AtEndEnvironment{equation}{\vspace{0.8em}}     % 增加公式底部空白
% 三线表上下加粗适配
\renewcommand{\toprule}{\specialrule{1pt}{0pt}{0pt}}
\renewcommand{\bottomrule}{\specialrule{1pt}{0pt}{0pt}}
% 代码导入配置
\newfontfamily\CodeNewRoman{CodeNewRomanNerdFont}[
  Path = static/font/CodeNewRoman/,
  Extension = .otf,
  UprightFont = CodeNewRomanNerdFont-Regular,
  BoldFont = CodeNewRomanNerdFont-Bold,
  ItalicFont = CodeNewRomanNerdFont-Italic
]
\def\lstbasicfont{\CodeNewRoman\footnotesize}
\definecolor{grey}{rgb}{0.8,0.8,0.8}
\definecolor{darkgreen}{rgb}{0,0.3,0}
\definecolor{darkblue}{rgb}{0,0,0.3}
\lstset{numbers=left,
  % language=Python,
  basicstyle=\CodeNewRoman\footnotesize,
  numberstyle=\small\color{gray},
  extendedchars=false,
  showstringspaces=false,
  breakatwhitespace=false,
  breaklines=true,
  captionpos=b,
  keywordstyle=\color{darkblue}\bfseries,%
  commentstyle=\color{darkgreen},%\itshape,%
  frame=shadowbox,
  rulesepcolor=\color{red!20!green!20!blue!20},
  lineskip=-2pt,
  % indexing
  numbers=left,
  numberstyle=\small,%
  % character display
  showstringspaces=false,
  showspaces=false,%
  tabsize=4,%
  % style
  stringstyle=\color{black}%
}

\AtBeginEnvironment{algorithmic}{\setlength{\itemsep}{0pt}}

%%%%%% 定制浮动图形和表格标题样式 %%%%%%
\makeatletter
\long\def\@makecaption#1#2{
   \vskip\abovecaptionskip
   \sbox\@tempboxa{\centering\wuhao\songti{#1\ #2} }
   \ifdim \wd\@tempboxa >\hsize
     \centering\wuhao\songti{#1\ #2} \par
   \else
     \global \@minipagefalse
     \hb@xt@\hsize{\hfil\box\@tempboxa\hfil}
   \fi
   \vskip\belowcaptionskip}
\makeatother
\captiondelim{~~~~} %用来控制longtable表头分隔符

%%%%%%%%%% Theorem Environment %%%%%%%%%%%%%%%%%
\theoremstyle{plain}
\theorembodyfont{\songti\rmfamily}
\theoremheaderfont{\heiti\rmfamily}
\newtheorem{theorem}{定理~}[chapter]
\newtheorem{lemma}{引理~}[chapter]
\newtheorem{axiom}{公理~}[chapter]
\newtheorem{proposition}{命题~}[chapter]
\newtheorem{prop}{性质~}[chapter]
\newtheorem{corollary}{推论~}[chapter]
\newtheorem{definition}{定义~}[chapter]
\newtheorem{conjecture}{猜想~}[chapter]
\newtheorem{example}{例~}[chapter]
\newtheorem{remark}{注~}[chapter]
%\newtheorem{algorithm}{算法~}[chapter]
\newenvironment{proof}{\noindent{\heiti 证明：}}{\hfill $ \square $ \vskip 4mm}
\theoremsymbol{$\square$}

%%%%%%%%%% Page: number, header and footer  %%%%%%%%%%%%%%%%%

\makeatletter
\renewcommand\frontmatter{\clearpage
  \@mainmatterfalse
  }
\makeatother

%%%%%%%%%%%% References %%%%%%%%%%%%%%%%%
\renewcommand{\bibname}{参考文献}
% 重定义参考文献样式，来自thu
\makeatletter
\renewenvironment{thebibliography}[1]{
    \titleformat{\chapter}{\raggedright\sihao\heiti}{\chaptername}{2em}{}
  %  \chapter*{\bibname}
   \wuhao
   \list{\@biblabel{\@arabic\c@enumiv}}
        {\renewcommand{\makelabel}[1]{##1\hfill}
         \settowidth\labelwidth{0 cm}
         \setlength{\labelsep}{0pt}
         \setlength{\itemindent}{0pt}
         \setlength{\leftmargin}{\labelwidth+\labelsep}
         \addtolength{\itemsep}{-0.7em}
         \usecounter{enumiv}
         \let\p@enumiv\@empty
         \renewcommand\theenumiv{\@arabic\c@enumiv}}
    \sloppy\frenchspacing
    \clubpenalty4000
    \@clubpenalty \clubpenalty
    \widowpenalty4000
    \interlinepenalty4000
    \sfcode`\.\@m}
   {\def\@noitemerr
     {\@latex@warning{Empty `thebibliography' environment}}
    \endlist\frenchspacing}
\makeatother

\addtolength{\bibsep}{-0.5em}     % 缩小参考文献间的垂直间距
\setlength{\bibhang}{2em}         % 每个条目自第二行起缩进的距离

% 参考文献引用作为上标出现
%\newcommand{\citeup}[1]{\textsuperscript{\cite{#1}}}
\makeatletter
    \def\@cite#1#2{\textsuperscript{[{#1\if@tempswa , #2\fi}]}}
\makeatother
%% 引用格式
\bibpunct{[}{]}{,}{s}{}{,}

%%%%%%%%%%%% Cover %%%%%%%%%%%%%%%%%
% 封面、摘要、版权、致谢格式定义
\makeatletter
\def\ctitle#1{\def\@ctitle{#1}}\def\@ctitle{}
\def\cdegree#1{\def\@cdegree{#1}}\def\@cdegree{}
\def\caffil#1{\def\@caffil{#1}}\def\@caffil{}
\def\csubject#1{\def\@csubject{#1}}\def\@csubject{}
\def\cgrade#1{\def\@cgrade{#1}}\def\@cgrade{}
\def\cauthor#1{\def\@cauthor{#1}}\def\@cauthor{}
\def\cnumber#1{\def\@cnumber{#1}}\def\@cnumber{}
\def\csupervisor#1{\def\@csupervisor{#1}}\def\@csupervisor{}
\def\crank#1{\def\@crank{#1}}\def\@crank{}
\def\cdate#1{\def\@cdate{#1}}\def\@cdate{}
\long\def\cabstract#1{\long\def\@cabstract{#1}}\long\def\@cabstract{}
\long\def\eabstract#1{\long\def\@eabstract{#1}}\long\def\@eabstract{}
\def\ckeywords#1{\def\@ckeywords{#1}}\def\@ckeywords{}
\def\ekeywords#1{\def\@ekeywords{#1}}\def\@ekeywords{}
\def\cheading#1{\def\@cheading{#1}}\def\@cheading{}
\def\thtitle#1{\def\@thtitle{#1}}\def\@thtitle{}

\pagestyle{fancy}
  \fancyhf{}
  \fancyhead[C]{\songti{\xiaowu{\@cheading}}}  % 页眉显示齐鲁工业大学 20XX 届本科毕业论文（设计）
  \fancyfoot[C]{\songti\xiaowu ~\thepage~}
\newlength{\@title@width}

\makeatletter
\newcommand{\covercontent}{
  \renewcommand\arraystretch{1.5}
  \setlength{\@title@width}{7cm}
    {
    \begin{tabular}{lc}
    \heiti\sihao{{学~部 \ （学~院）}}&  \underline{\makebox[\@title@width][c]{\@caffil}} \\[0.35em]
    \heiti\sihao{{专\quad 业\quad 班\quad 级}} &  \underline{\makebox[\@title@width][c]{\@csubject}} \\[0.34em]
    \heiti\sihao{{学\quad 生\quad 姓\quad 名}}  &  \underline{\makebox[\@title@width][c]{\@cauthor}}\\[0.34em]
    \heiti\sihao{{学\qquad\qquad\ \ \  号}} &  \underline{\makebox[\@title@width][c]{\@cnumber}} \\[0.34em]
    \heiti\sihao{{导\quad 师\quad 姓\quad 名}} &  \underline{\makebox[\@title@width][c]{\@csupervisor}} \\
    \end{tabular}
    }
}

% 封面
\newcommand{\makecover}{
  \begin{titlepage}
    \begin{center}
      \phantomsection
      \pdfbookmark[-1]{\@ctitle}{ctitle}

      \vspace*{24.5pt}

      \begin{figure}[h]
        \centering
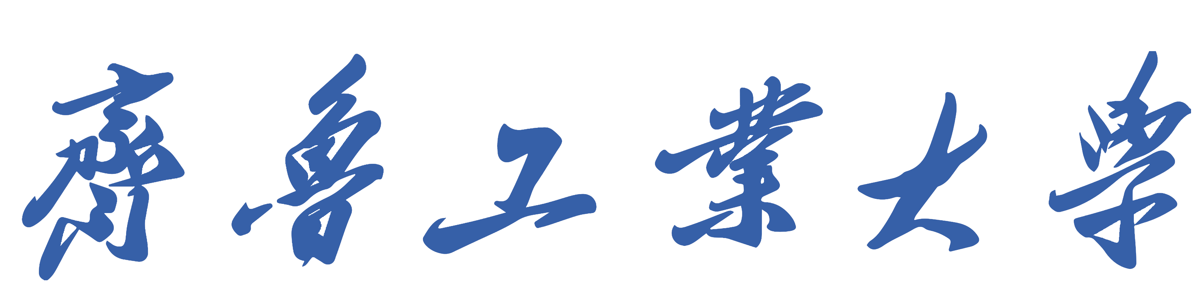
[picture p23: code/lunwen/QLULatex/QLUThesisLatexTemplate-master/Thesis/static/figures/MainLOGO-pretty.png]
        \ 
      \end{figure}

      \vspace{-1pt}

      \heiti\maintitle{\textbf{\renewcommand{\CJKglue}{\hskip 0.16em}
        本科毕业论文（设计） \
        }}

      \vspace{76pt}

      \heiti\sanhao{\textbf{\@thtitle}}

      \vspace{3.8cm}

      \covercontent

      \vspace{3.25cm}
    
      \heiti\sihao{{\@cdate}}

    \end{center}
    
  \end{titlepage}
}

% 扉页
\newcommand{\makesubcover}{%
  \begin{titlepage}
    \begin{center}
      \vspace*{3.48cm}

      \heiti\xiaoyi{\textbf{\renewcommand{\CJKglue}{\hskip 0.22em}
        本科毕业论文（设计）
        }}

      \vspace{66pt}

      \heiti\sanhao{\textbf{\@thtitle}}

      \vspace{4.55cm}

      \covercontent

      \vspace{3.25cm}

      \heiti\sihao{{\@cdate}}
    \end{center}
  \end{titlepage}
}
\makeatother

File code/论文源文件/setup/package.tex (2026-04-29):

% !Mode:: "TeX:UTF-8"

%*  Authors: 张井   Jing Zhang: prayever@gmail.com     天津大学2010级管理与经济学部信息管理与信息系统专业硕士生
%*           余蓝涛 Lantao Yu: lantaoyu1991@gmail.com  天津大学2008级精密仪器与光电子工程学院测控技术与仪器专业本科生

%! ************************************************************* %!
%!              _       __                 _                     %!
%!             | |     / /___ __________  (_)___  ____ _         %!
%!             | | /| / / __ `/ ___/ __ \/ / __ \/ __ `/         %!
%!             | |/ |/ / /_/ / /  / / / / / / / / /_/ /          %!
%!             |__/|__/\__,_/_/  /_/ /_/_/_/ /_/\__, /           %!
%!                                             /____/            %!
%!          如果您不知道如何修改LaTeX,请勿随意尝试修改本文件!           %!
%! ************************************************************* %!

%%%%%%%%%% Package %%%%%%%%%%%%
% \usepackage{CJK} % 与 ctex/xeCJK 冲突，已禁用
\usepackage{lmodern}
\usepackage[T1]{fontenc}
\usepackage{graphicx}                       % 支持插图处理
\usepackage[a4paper,
    top=25truemm, bottom=25truemm,   % 上下边距
    left=25truemm, right=25truemm,   % 左右边距
    head=10truemm,                    % 页眉高度
    headsep=5.5truemm,               % 页眉与正文间距
    foot=7truemm]                 % 页脚高度
{geometry}
\usepackage{setspace}
% \setlength{\headsep}{-2mm}

\usepackage{etoolbox}                              

\usepackage[squaren]{SIunits}               % 支持国际标准单位
\usepackage{svg}							%导入svg格式的宏包
\usepackage{titlesec}                       % 控制标题的宏包
\usepackage{titletoc}                       % 控制目录的宏包
\usepackage{fancyhdr}                       % fancyhdr宏包 支持页眉和页脚的相关定义
%\usepackage{ctex}                     % 支持中文显示
% \usepackage{CJKpunct}                       % 与 ctex/xeCJK 冲突，已禁用
\usepackage{color}                          % 支持彩色
\usepackage{amsmath}                        % AMSLaTeX宏包 用来排出更加漂亮的公式
\usepackage{mathtools}                      % 对 amsmath 的功能补充
\usepackage{amssymb}                        % 数学符号生成命令
\usepackage[below]{placeins}    %允许上一个section的浮动图形出现在下一个section的开始部分,还提供\FloatBarrier命令,使所有未处理的浮动图形立即被处理
\usepackage{float}                          % 提供 [H] 浮动位置选项，尽量固定图片位置
\usepackage{multirow}                       % 使用Multirow宏包，使得表格可以合并多个row格
\usepackage{booktabs}                       % 表格，横的粗线； \specialrule{1pt}{0pt}{0pt}
\usepackage{longtable}                      % 支持跨页的表格。
\usepackage{tabularx}                       % 自动设置表格的列宽
\usepackage{subfigure}                      % 支持子图 %centerlast 设置最后一行是否居中
\usepackage[subfigure]{ccaption}            % 支持子图的中文标题
\usepackage[sort&compress,numbers]{natbib}  % 支持引用缩写的宏包
\usepackage{enumitem}                       % 使用enumitem宏包,改变列表项的格式
\usepackage{calc}                           % 长度可以用+ - * / 进行计算
\usepackage{txfonts}                        % 字体宏包
\usepackage{bm}                             % 处理数学公式中的黑斜体的宏包
\usepackage[amsmath,thmmarks,hyperref]{ntheorem}  % 定理类环境宏包，其中 amsmath 选项用来兼容 AMS LaTeX 的宏包
\usepackage{CJKnumb}                        % 提供将阿拉伯数字转换成中文数字的命令
\usepackage{indentfirst}                    % 首行缩进宏包
% \usepackage{CJKutf8}                        % 与 ctex/xeCJK 冲突，已禁用
%\usepackage{hypbmsec}                      % 用来控制书签中标题显示内容
%画图
\usepackage{pgfplots}
\usepackage{tikz}

\newcommand{\tabincell}[2]{\begin{tabular}{@{}#1@{}}#2\end{tabular}}
\usepackage{xcolor}
%支持代码环境
\usepackage{listings}

%支持算法环境
\usepackage[boxed,ruled,lined,linesnumbered]{algorithm2e}
% \usepackage{algorithmic}

\usepackage{array}
\newcommand{\PreserveBackslash}[1]{\let\temp=\\#1\let\\=\temp}
\newcolumntype{C}[1]{>{\PreserveBackslash\centering}p{#1}}
\newcolumntype{R}[1]{>{\PreserveBackslash\raggedleft}p{#1}}
\newcolumntype{L}[1]{>{\PreserveBackslash\raggedright}p{#1}}
\renewcommand{\arraystretch}{1.18}

\usepackage{xurl}                           % 改善长 URL 自动断行

\def\atemp{xelatex}\ifx\atemp\usewhat
\usepackage[unicode,
            pdfstartview=FitH,
            bookmarksnumbered=true,
            bookmarksopen=true,
            colorlinks=false,
            pdfborder={0 0 1},
            citecolor=blue,
            linkcolor=red,
            anchorcolor=green,
            urlcolor=blue,
            breaklinks=true
            ]{hyperref}
\fi
\hypersetup{
	colorlinks=true,
	linkcolor=black
}

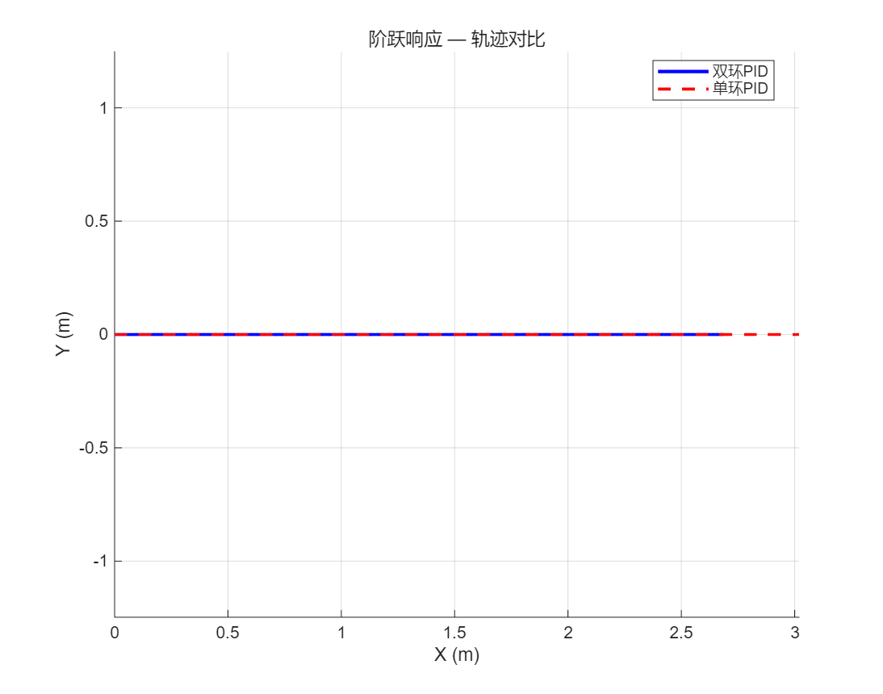
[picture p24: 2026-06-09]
code/fangzhen/matlab/figures/pid_step_1轨迹对比.png

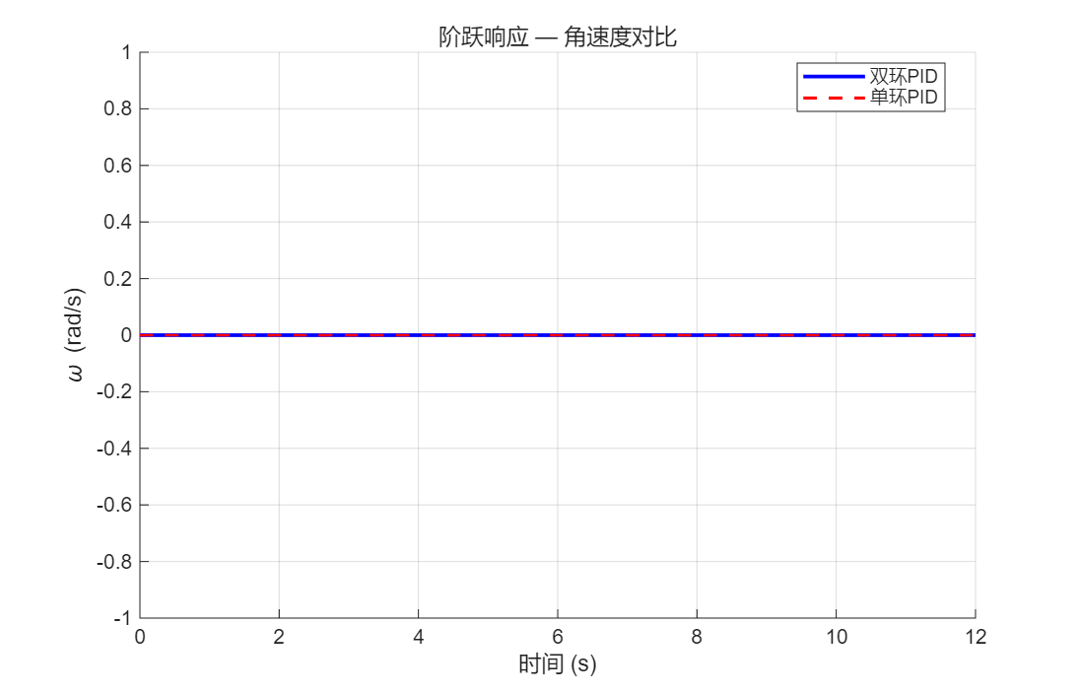
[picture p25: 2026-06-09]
code/fangzhen/matlab/figures/pid_step_3角速度对比.png

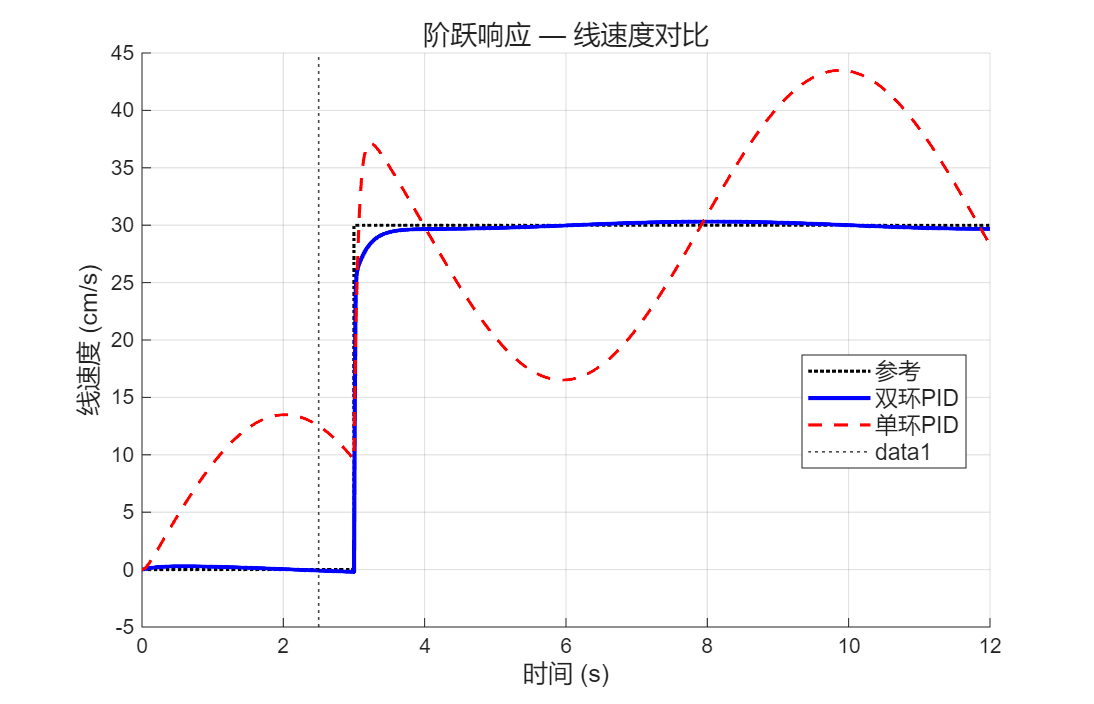
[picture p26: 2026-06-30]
王子煜-202201230042-智能仓储自主移动机器人结构设计与控制/matlab/figures/pid_step_2线速度对比.png

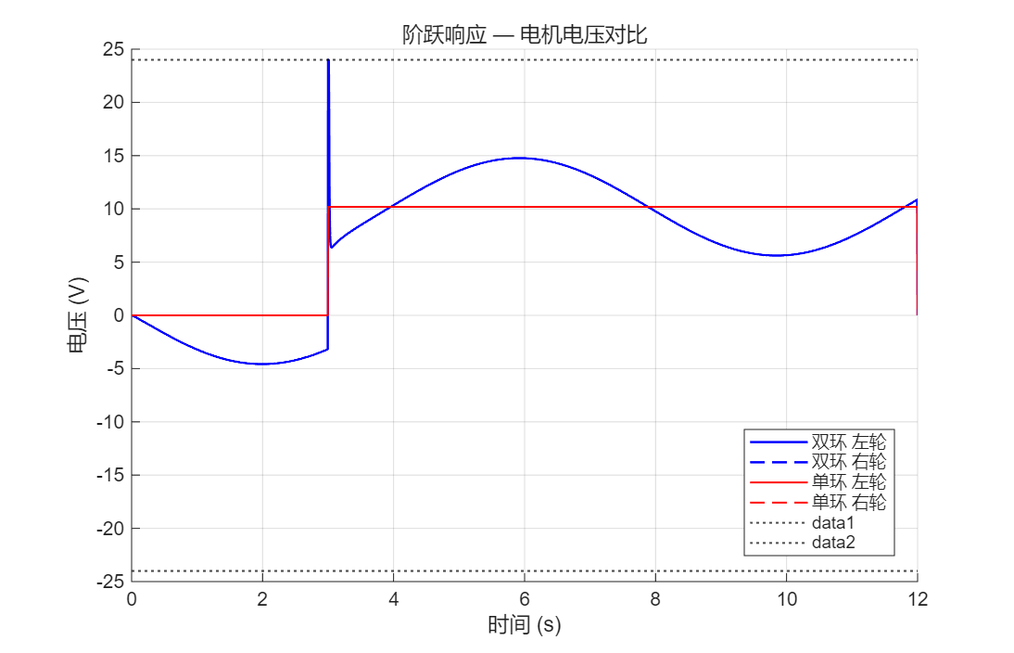
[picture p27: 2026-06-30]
王子煜-202201230042-智能仓储自主移动机器人结构设计与控制/matlab/figures/pid_step_4电压对比.png

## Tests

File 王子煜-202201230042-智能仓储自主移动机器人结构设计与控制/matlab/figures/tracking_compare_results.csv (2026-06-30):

算法 | RMS_cm | MAX_cm | OmegaRMS_rads | SimTime_s | LostRatio_pct
PID+前馈 | 0.7313 | 1.3293 | 0.2001 | 55.78 | 0.00
Stanley | 3.0108 | 5.1185 | 0.1660 | 56.63 | 0.00
Pure Pursuit | 0.4057 | 1.2078 | 0.1533 | 55.75 | 0.00

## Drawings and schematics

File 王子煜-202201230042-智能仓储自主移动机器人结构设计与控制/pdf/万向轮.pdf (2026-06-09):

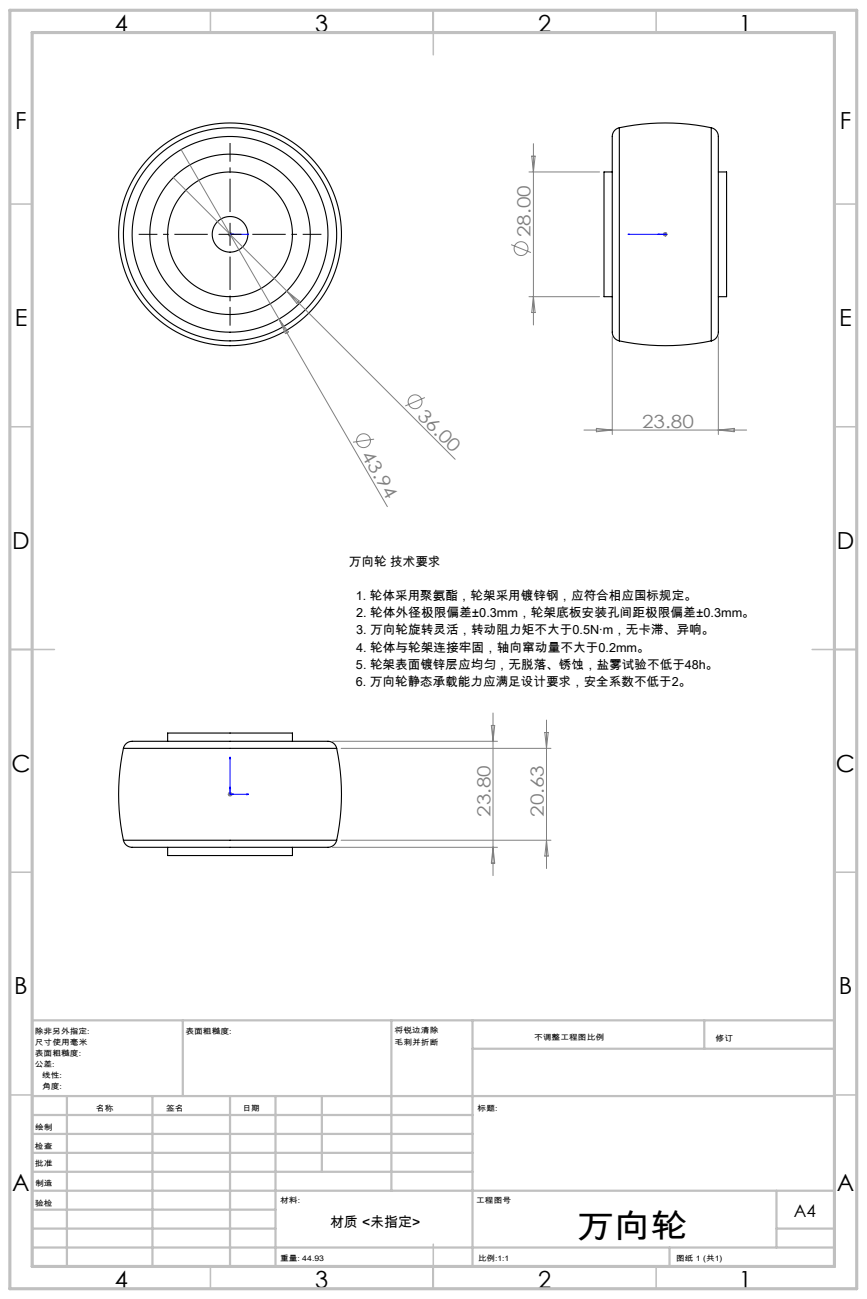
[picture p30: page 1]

万向轮 技术要求
1. 轮体采用聚氨酯，轮架采用镀锌钢，应符合相应国标规定。
2. 轮体外径极限偏差±0.3mm，轮架底板安装孔间距极限偏差±0.3mm。
3. 万向轮旋转灵活，转动阻力矩不大于0.5N·m，无卡滞、异响。
4. 轮体与轮架连接牢固，轴向窜动量不大于0.2mm。
5. 轮架表面镀锌层应均匀，无脱落、锈蚀，盐雾试验不低于48h。
6. 万向轮静态承载能力应满足设计要求，安全系数不低于2。

绘制
检查
批准
制造
验检 | | | | 材料: | 工程图号 万向轮 | A4 材质 <未指定>

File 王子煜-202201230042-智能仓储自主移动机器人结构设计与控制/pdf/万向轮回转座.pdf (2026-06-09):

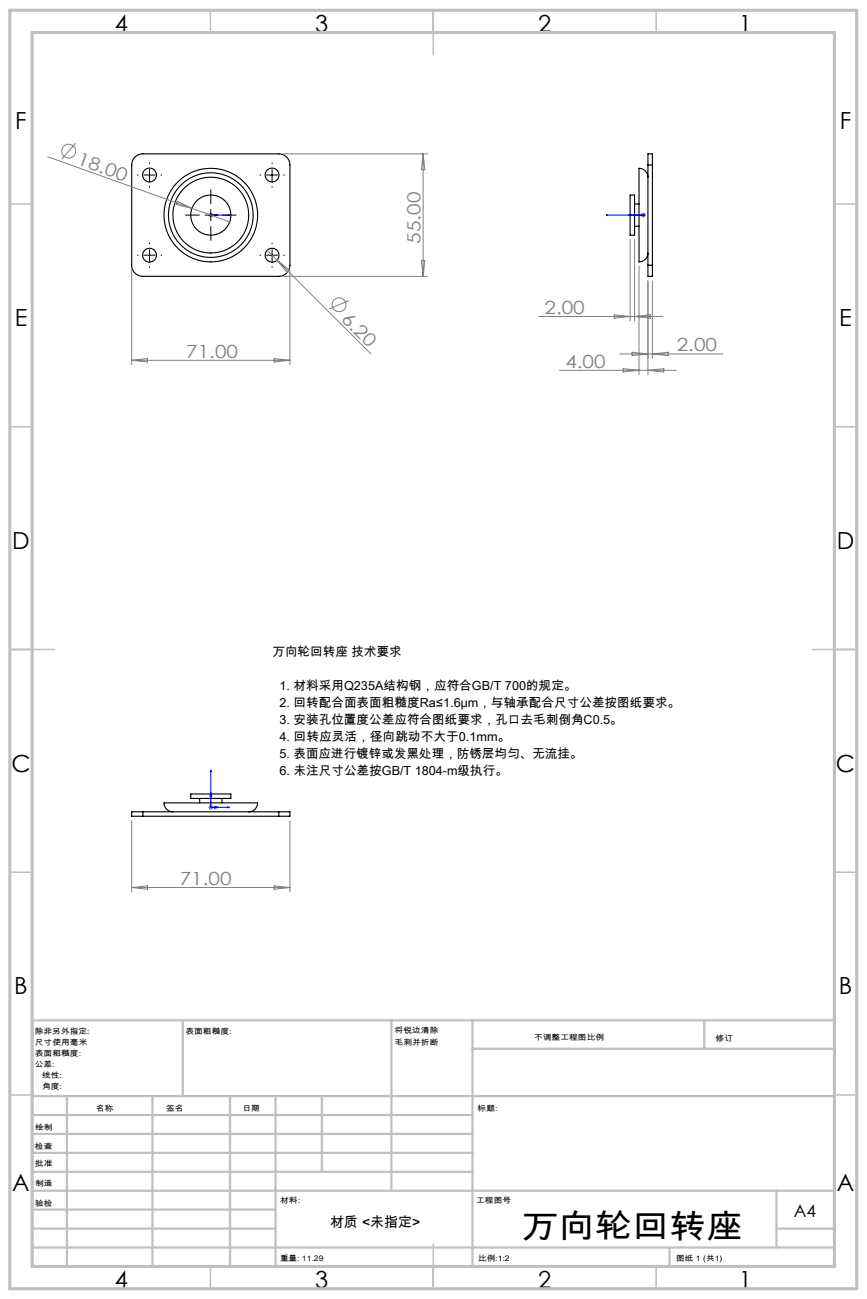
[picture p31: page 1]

万向轮回转座 技术要求
1. 材料采用Q235A结构钢，应符合GB/T 700的规定。
2. 回转配合面表面粗糙度Ra≤1.6μm，与轴承配合尺寸公差按图纸要求。
3. 安装孔位置度公差应符合图纸要求，孔口去毛刺倒角C0.5。
4. 回转应灵活，径向跳动不大于0.1mm。
5. 表面应进行镀锌或发黑处理，防锈层均匀、无流挂。
6. 未注尺寸公差按GB/T 1804-m级执行。

绘制
检查
批准
制造
验检 | | | | 材料: | 工程图号 万向轮回转座 | A4 材质 <未指定>

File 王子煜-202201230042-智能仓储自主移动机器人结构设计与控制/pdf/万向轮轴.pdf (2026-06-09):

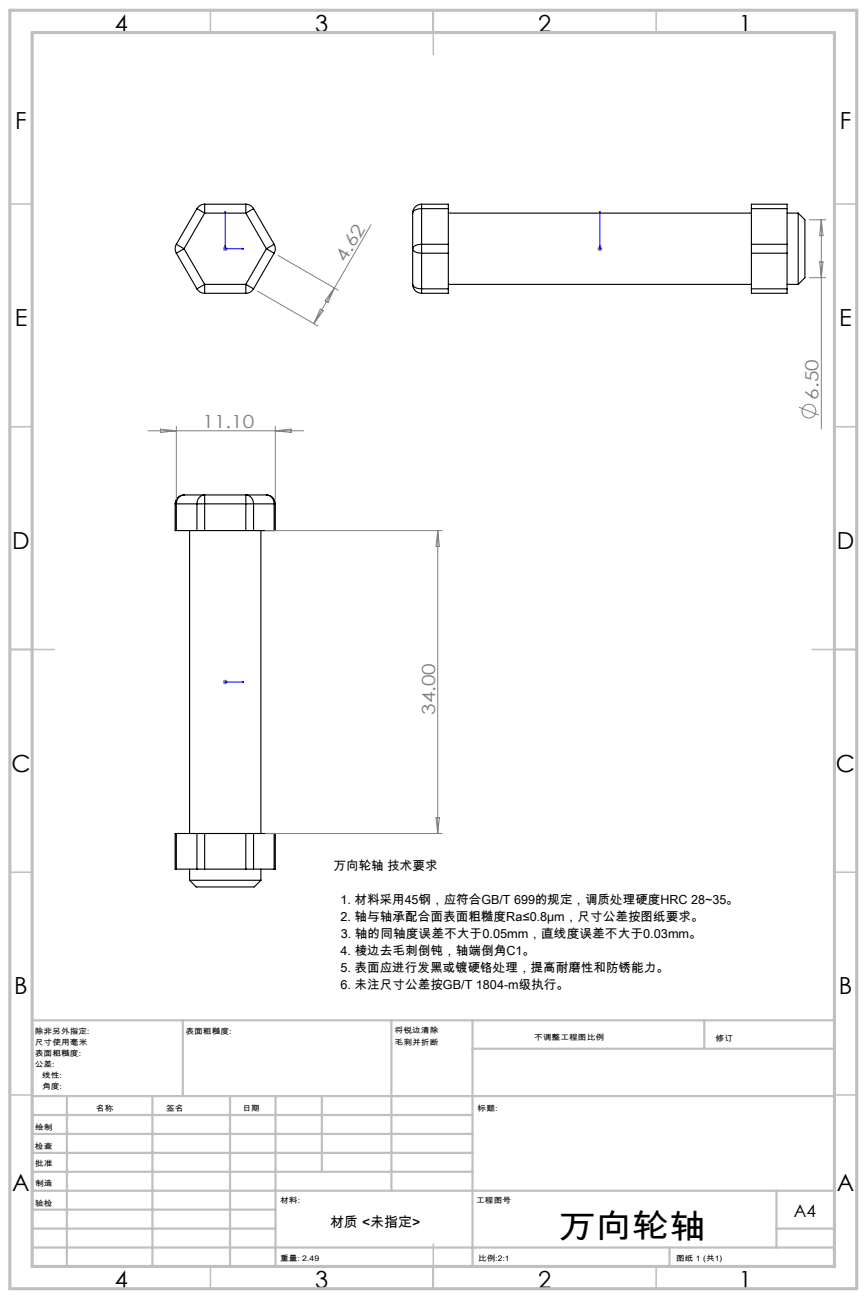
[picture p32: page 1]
万向轮轴 技术要求; 1. 材料采用45钢，应符合GB/T 699的规定，调质处理硬度HRC 28~35。 2. 轴与轴承配合面表面粗糙度Ra≤0.8μm，尺寸公差按图纸要求。 3. 轴的同轴度误差不大于0.05mm，直线度误差不大于0.03mm。 4. 棱边去毛刺倒钝，轴端倒角C1。 5. 表面应进行发黑或镀硬铬处理，提高耐磨性和防锈能力。 6. 未注尺寸公差按GB/T 1804-m级执行。

绘制
检查
批准
制造
验检 | | | | 材料: | 工程图号 万向轮轴 | A4 材质 <未指定>

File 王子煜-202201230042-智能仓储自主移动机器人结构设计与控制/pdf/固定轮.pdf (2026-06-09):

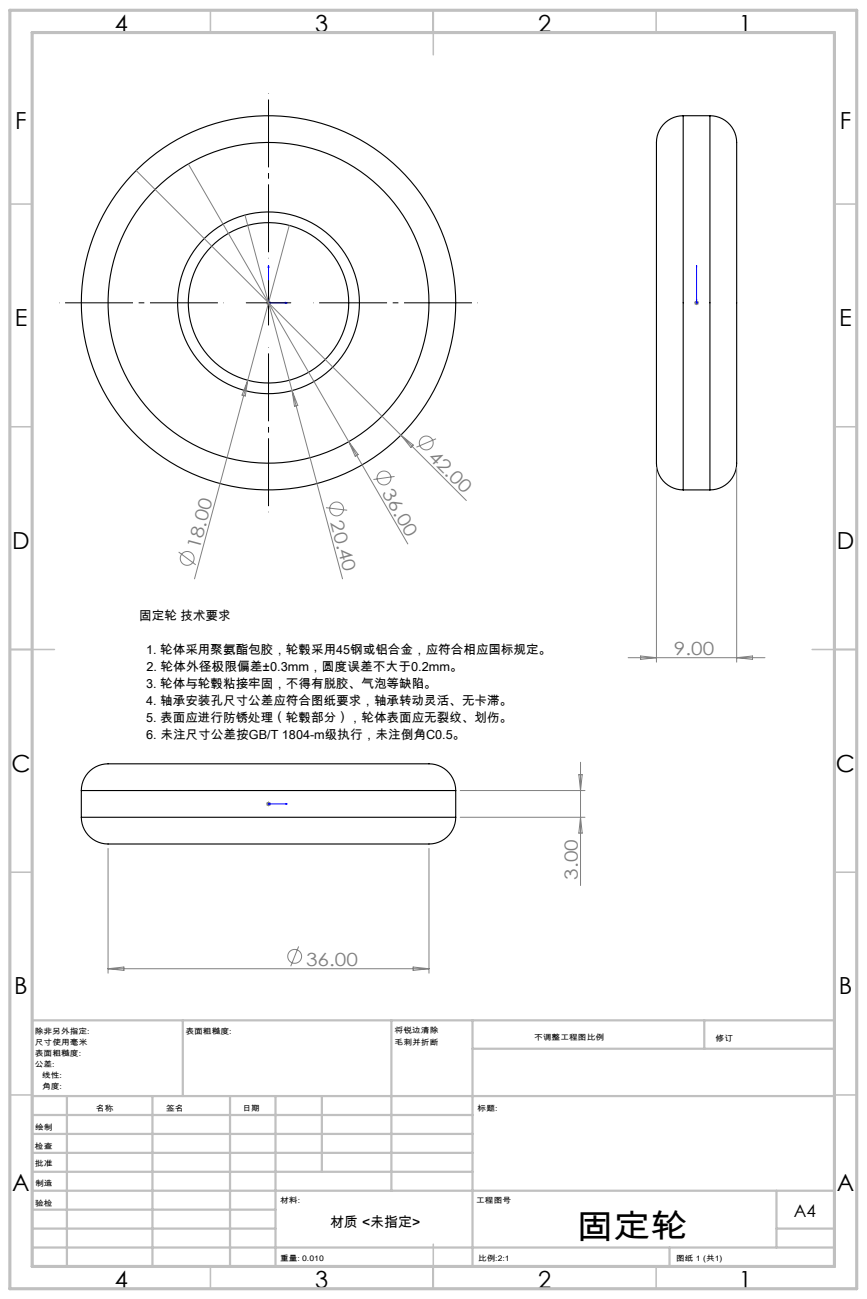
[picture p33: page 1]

固定轮 技术要求
1. 轮体采用聚氨酯包胶，轮毂采用45钢或铝合金，应符合相应国标规定。
2. 轮体外径极限偏差±0.3mm，圆度误差不大于0.2mm。
3. 轮体与轮毂粘接牢固，不得有脱胶、气泡等缺陷。
4. 轴承安装孔尺寸公差应符合图纸要求，轴承转动灵活、无卡滞。
5. 表面应进行防锈处理（轮毂部分），轮体表面应无裂纹、划伤。
6. 未注尺寸公差按GB/T 1804-m级执行，未注倒角C0.5。

绘制
检查
批准
制造
验检 | | | | 材料: | 工程图号 固定轮 | A4 材质 <未指定>

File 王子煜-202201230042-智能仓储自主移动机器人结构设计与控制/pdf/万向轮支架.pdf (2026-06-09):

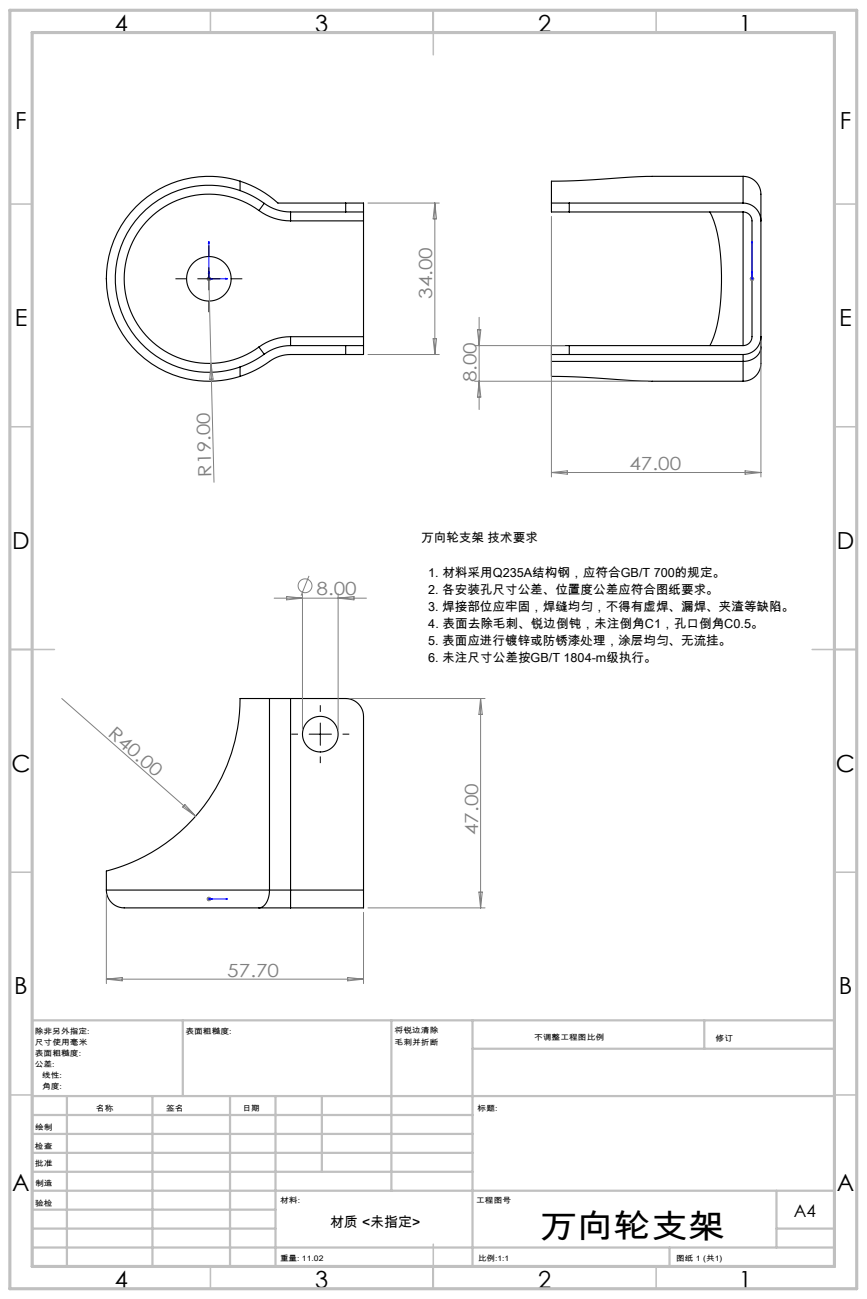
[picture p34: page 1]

万向轮支架 技术要求
1. 材料采用Q235A结构钢，应符合GB/T 700的规定。
2. 各安装孔尺寸公差、位置度公差应符合图纸要求。
3. 焊接部位应牢固，焊缝均匀，不得有虚焊、漏焊、夹渣等缺陷。
4. 表面去除毛刺、锐边倒钝，未注倒角C1，孔口倒角C0.5。
5. 表面应进行镀锌或防锈漆处理，涂层均匀、无流挂。
6. 未注尺寸公差按GB/T 1804-m级执行。

绘制
检查
批准
制造
验检 | | | | 材料: | 工程图号 万向轮支架 | A4 材质 <未指定>

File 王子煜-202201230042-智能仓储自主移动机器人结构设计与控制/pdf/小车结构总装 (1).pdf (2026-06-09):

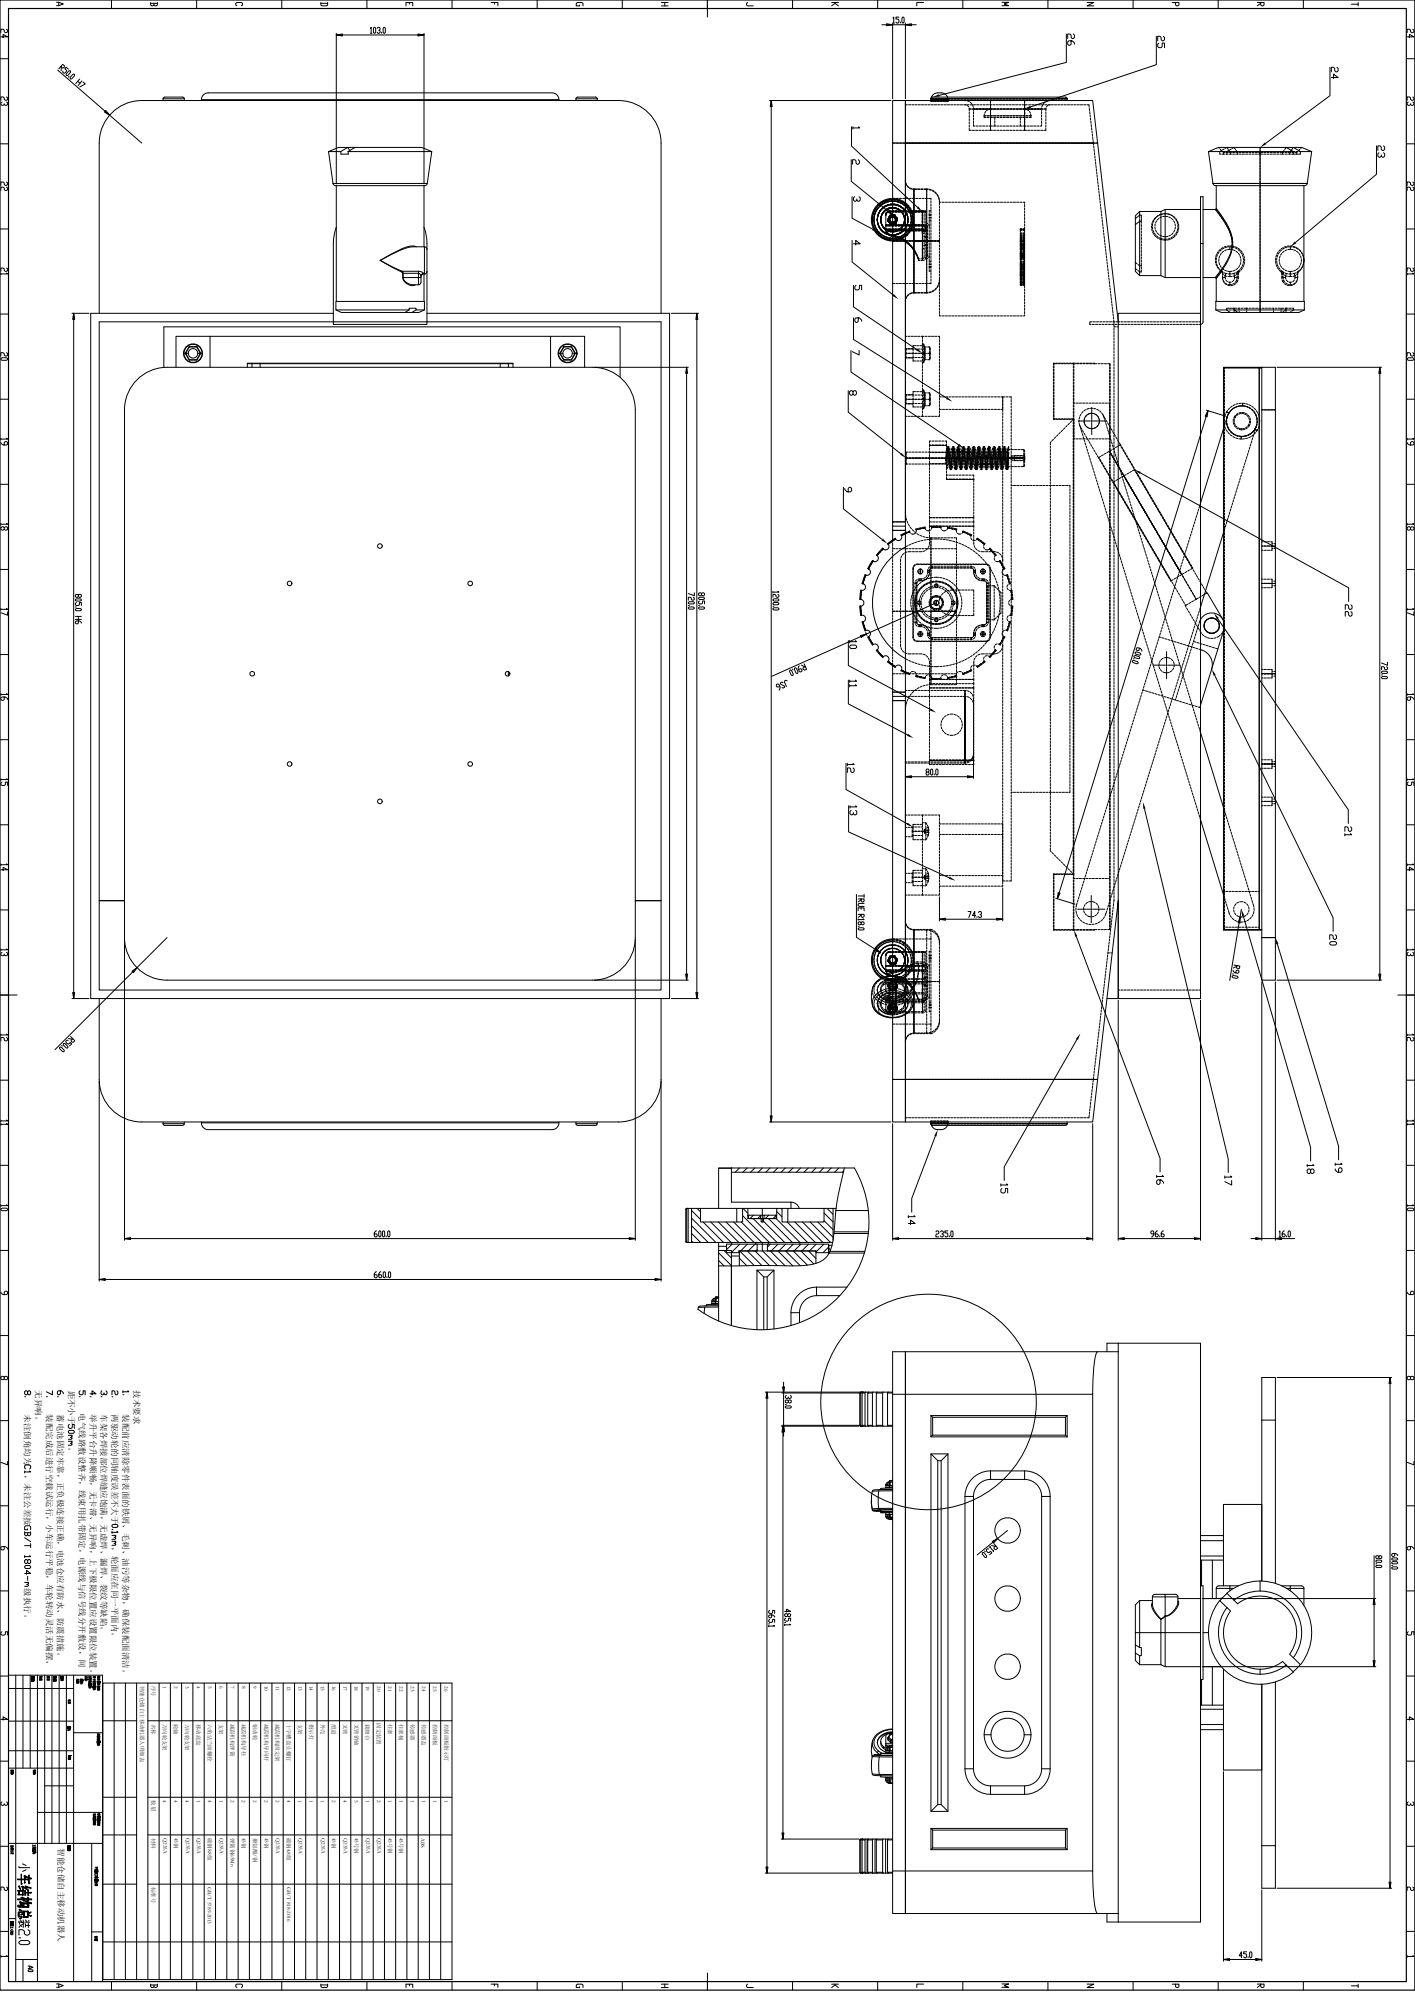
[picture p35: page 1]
26 控制面板指示灯 1; 25 控制面板 1; 24 传感器盖 1 ABS; 23 传感器 1; 22 柱塞桶 1 45号钢; 20 固定装置 2 Q235A; 19 载物台 1 Q235A; 18 叉臂销轴 5 45号钢; 14 指示灯 1; 12 十字槽盘头螺钉 4 碳钢4.8级 GB/T 818-2016; 11 减震机构固定架 2 Q235A; 10 减震机构导向杆 2 45钢; 9 驱动轮 2 聚氨酯/钢; 8 减震机构导柱 2 45钢; 7 减震机构弹簧 2 弹簧钢65Mn; 5 六角法兰面螺栓 4 碳钢8.8级 GB/T 5789-2013; 4 移动底盘 1 Q235A; 3 万向轮支架 4 Q235A; 1 万向轮支架 4 Q235A; 智能仓储自主移动机器人明细表 技术要求; 两驱动轮的同轴度误差不大于; ，轮面应在同一平面内。; 距不小于 。; 无异响。; 智能仓储自主移动机器人

未注倒角均为 ，未注公差按 级执行。

装配完成后进行空载试运行，小车运行平稳，车轮转动灵活无偏摆、

蓄电池固定牢靠，正负极连接正确，电池仓应有防水、防震措施。

电气线路敷设整齐，线束用扎带固定，电源线与信号线分开敷设，间

举升平台升降顺畅，无卡滞、无异响，上下极限位置应设置限位装置。

车架各焊接部位焊缝应饱满，无虚焊、漏焊、裂纹等缺陷。

装配前应清除零件表面的铁屑、毛刺、油污等杂物，确保装配面清洁。

序号 名称 数量 材料 标准号

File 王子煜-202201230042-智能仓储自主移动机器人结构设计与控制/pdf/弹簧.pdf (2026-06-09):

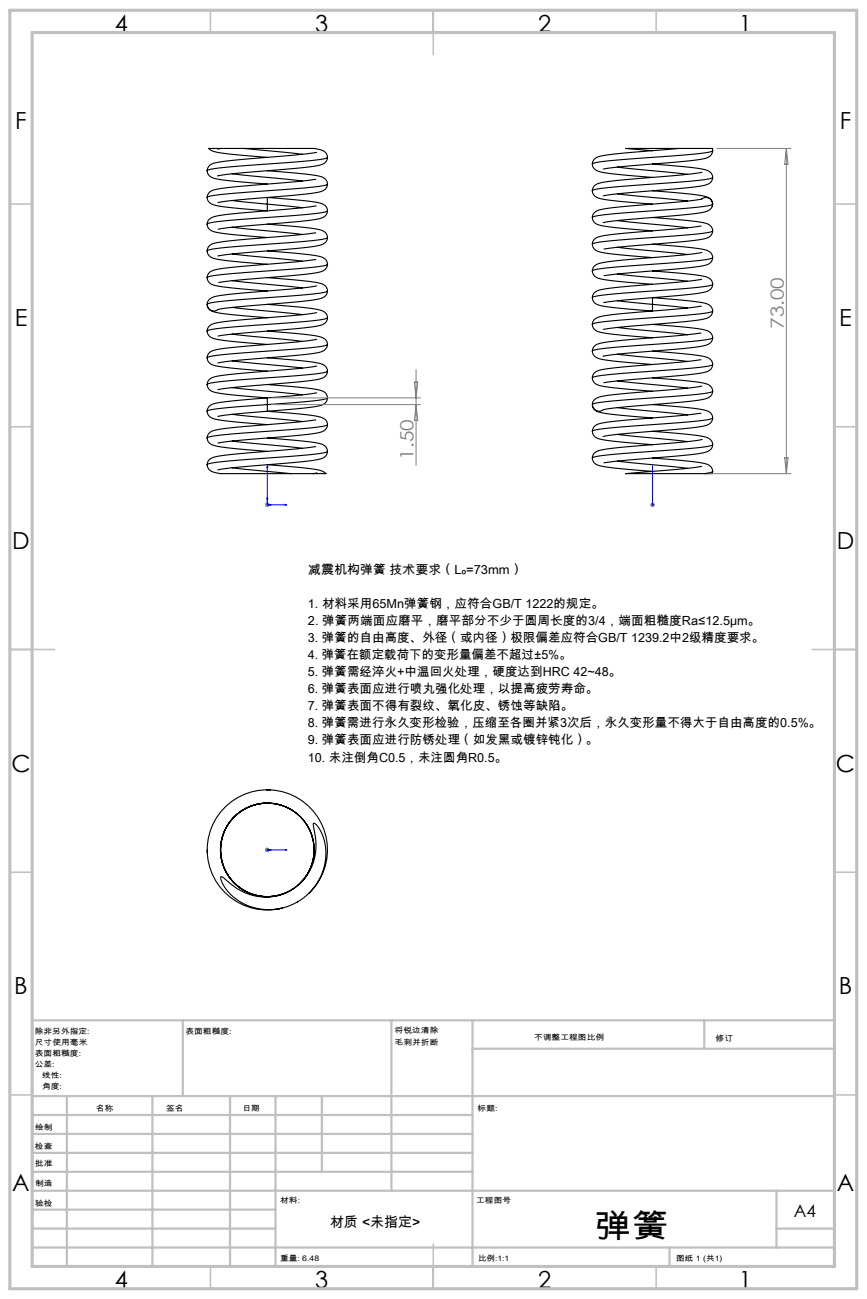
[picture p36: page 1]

减震机构弹簧 技术要求（L₀=73mm）
1. 材料采用65Mn弹簧钢，应符合GB/T 1222的规定。
2. 弹簧两端面应磨平，磨平部分不少于圆周长度的3/4，端面粗糙度Ra≤12.5μm。
3. 弹簧的自由高度、外径（或内径）极限偏差应符合GB/T 1239.2中2级精度要求。
4. 弹簧在额定载荷下的变形量偏差不超过±5%。
5. 弹簧需经淬火+中温回火处理，硬度达到HRC 42~48。
6. 弹簧表面应进行喷丸强化处理，以提高疲劳寿命。
7. 弹簧表面不得有裂纹、氧化皮、锈蚀等缺陷。
8. 弹簧需进行永久变形检验，压缩至各圈并紧3次后，永久变形量不得大于自由高度的0.5%。
9. 弹簧表面应进行防锈处理（如发黑或镀锌钝化）。
10. 未注倒角C0.5，未注圆角R0.5。

绘制
检查
批准
制造
验检 | | | | 材料: | 工程图号 弹簧 | A4 材质 <未指定>

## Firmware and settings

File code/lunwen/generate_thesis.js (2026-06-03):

const fs = require('fs');
const { Document, Packer, Paragraph, TextRun, Table, TableRow, TableCell,
        Header, Footer, AlignmentType, LevelFormat,
        HeadingLevel, BorderStyle, WidthType, ShadingType,
        PageNumber, PageBreak, TableOfContents } = require('docx');

// ===== Helper functions =====
function p(text, opts = {}) {
  const runs = [];
  if (typeof text === 'string') {
    runs.push(new TextRun({ text, bold: opts.bold, font: opts.font || 'Times New Roman', size: opts.size || 24 }));
  } else if (Array.isArray(text)) {
    text.forEach(r => runs.push(new TextRun(r)));
  }
  return new Paragraph({
    children: runs,
    alignment: opts.alignment,
    spacing: { line: opts.line || 360, before: opts.before || 0, after: opts.after || 0 },
    indent: opts.indent ? { firstLine: opts.indent } : undefined,
    heading: opts.heading,
    pageBreakBefore: opts.pageBreakBefore,
  });
}

function h1(text) {
  return new Paragraph({
    heading: HeadingLevel.HEADING_1,
    alignment: AlignmentType.CENTER,
    spacing: { before: 240, after: 240, line: 360 },
    children: [new TextRun({ text, bold: true, font: 'SimHei', size: 32 })],
  });
}

function h2(text) {
  return new Paragraph({
    heading: HeadingLevel.HEADING_2,
    spacing: { before: 180, after: 120, line: 360 },
    children: [new TextRun({ text, bold: true, font: 'SimHei', size: 28 })],
  });
}

function h3(text) {
  return new Paragraph({
    heading: HeadingLevel.HEADING_3,
    spacing: { before: 120, after: 120, line: 360 },
    children: [new TextRun({ text, bold: true, font: 'SimHei', size: 28 })],
  });
}

function bodyPara(text) {
  return p(text, { indent: 480, font: 'SimSun', size: 24, line: 360 });
}

function bodyParaNoIndent(text) {
  return p(text, { font: 'SimSun', size: 24, line: 360 });
}

function emptyLine() {
  return new Paragraph({ spacing: { after: 0, line: 360 }, children: [] });
}

function refItem(text) {
  return p(text, { font: 'SimSun', size: 20, line: 360 });
}

// ===== Cover page content =====
function coverPage() {
  return [
    new Paragraph({ spacing: { before: 600 }, children: [] }),
    new Paragraph({
      alignment: AlignmentType.CENTER,
      spacing: { after: 200, line: 360 },
      children: [new TextRun({ text: '齐鲁工业大学', font: 'SimSun', size: 44, bold: true })],
    }),
    new Paragraph({
      alignment: AlignmentType.CENTER,
      spacing: { after: 400, line: 360 },
      children: [new TextRun({ text: '本科毕业论文（设计）', font: 'SimSun', size: 44, bold: true })],
    }),
    new Paragraph({ spacing: { before: 400 }, children: [] }),
    new Paragraph({
      alignment: AlignmentType.CENTER,
      spacing: { after: 600, line: 360 },
      children: [new TextRun({ text: '智能仓储自主移动机器人结构设计与控制', font: 'SimHei', size: 32, bold: true })],
    }),
    new Paragraph({ spacing: { before: 200 }, children: [] }),
    // Info table
    ...[
      ['学部（学院）', '机械工程学院'],
      ['专业班级', '机器人（SI）22-2'],
      ['学生姓名', '王子煜'],
      ['学号', '202201230042'],
      ['导师姓名', '刘鹏博'],
    ].map(([label, value]) => new Paragraph({
      alignment: AlignmentType.CENTER,
      spacing: { after: 120, line: 360 },
      children: [
        new TextRun({ text: `${label}    `, font: 'SimSun', size: 28 }),
        new TextRun({ text: value, font: 'SimSun', size: 28, underline: {} }),
      ],
    })),
    new Paragraph({ spacing: { before: 600 }, children: [] }),
    new Paragraph({
      alignment: AlignmentType.CENTER,
      spacing: { line: 360 },
      children: [new TextRun({ text: '2026年03月10日', font: 'SimSun', size: 28 })],
    }),
  ];
}

// ===== Declaration page =====
function declarationPage() {
  return [
    new Paragraph({
      alignment: AlignmentType.CENTER,
      spacing: { before: 400, after: 240, line: 360 },
      children: [new TextRun({ text: '原创性声明', font: 'SimHei', size: 32, bold: true })],
    }),
    bodyPara('本人郑重声明：所呈交的毕业论文（设计），是本人在指导教师的指导下独立研究、撰写的成果。论文（设计）中引用他人的文献、数据、图件、资料，均已在论文（设计）中加以说明，除此之外，本论文（设计）不含任何其他个人或集体已经发表或撰写的成果作品。对本文研究做出重要贡献的个人和集体，均已在文中作了明确说明并表示了谢意。本声明的法律结果由本人承担。'),
    new Paragraph({ spacing: { before: 600 }, children: [] }),
    new Paragraph({
      alignment: AlignmentType.RIGHT,
      spacing: { line: 360 },
      children: [new TextRun({ text: '毕业论文（设计）作者签名：', font: 'SimSun', size: 24 })],
    }),
    new Paragraph({
      alignment: AlignmentType.RIGHT,
      spacing: { line: 360 },
      children: [new TextRun({ text: '        年    月    日', font: 'SimSun', size: 24 })],
    }),
    new Paragraph({ children: [new PageBreak()] }),
    new Paragraph({
      alignment: AlignmentType.CENTER,
      spacing: { before: 400, after: 240, line: 360 },
      children: [new TextRun({ text: '齐鲁工业大学本科毕业论文（设计）', font: 'SimHei', size: 32, bold: true })],
    }),
    new Paragraph({
      alignment: AlignmentType.CENTER,
      spacing: { after: 240, line: 360 },
      children: [new TextRun({ text: '使用授权说明', font: 'SimHei', size: 32, bold: true })],
    }),
    bodyPara('本毕业论文（设计）作者完全了解学校有关保留、使用毕业论文（设计）的规定，即：学校有权保留、送交论文（设计）的复印件，允许论文（设计）被查阅和借阅，学校可以公布论文（设计）的全部或部分内容，可以采用影印、扫描等复制手段保存本论文（设计）。'),
    new Paragraph({ spacing: { before: 400 }, children: [] }),
    new Paragraph({
      spacing: { line: 360 },
      children: [new TextRun({ text: '指导教师签名：                  ', font: 'SimSun', size: 24 })],
    }),
    new Paragraph({
      spacing: { line: 360 },
      children: [new TextRun({ text: '毕业论文（设计）作者签名：                  ', font: 'SimSun', size: 24 })],
    }),
    new Paragraph({
      spacing: { line: 360 },
      children: [new TextRun({ text: '      年    月    日                  年    月    日', font: 'SimSun', size: 24 })],
    }),
  ];
}
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

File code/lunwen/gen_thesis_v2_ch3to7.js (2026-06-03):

const { h1Text, h2Text, h3Text, bodyP, centerP, emptyP, Paragraph, TextRun, PageBreak,
  FONT_SONG, FONT_HEI, FONT_TNR, SIZE_SANHAO, SIZE_XIAOSI, SIZE_WUHAO, LINE_SPACING, AlignmentType } = require('./gen_thesis_v2.js');
const { eq, eqCentered, tbl, fig, figNote } = require('./gen_thesis_v2_helpers.js');

// ===== CHAPTER 3 (FULL) =====
function ch3() {
  return [
    new Paragraph({ children: [new PageBreak()] }),
    h1Text('第3章 智能仓储移动机器人机械结构设计'),
    bodyP('本设计的智能仓储移动小车采用差速驱动方式，由交流伺服电机驱动两个独立的驱动轮。小车搭载剪叉式升降机构，可实现货物的垂直搬运。整体结构兼具运动灵活性和承载能力，能够满足复杂仓储环境下的物流配送需求。其总体结构主要由车身、驱动轮、升降机构和控制系统四大部分组成。'),
    h2Text('3.1 剪叉式垂直升降机构设计'),
    bodyP('剪叉式垂直升降机构是本文所设计智能仓储移动机器人的核心功能模块，承担货物的垂直搬运任务。与固定高度的搬运平台相比，引入升降机构后，机器人可以在不改变自身位置的情况下完成货物在不同高度货架层之间的取放操作，显著拓展了作业范围和场景适应性。'),
    h3Text('3.1.1 机构选型依据'),
    bodyP('在仓储搬运场景中，升降机构需同时满足以下要求：（1）承载能力不低于50 kg；（2）升降行程覆盖仓库常用货架高度范围；（3）平台在升降全过程中保持水平姿态；（4）机构收起时占用高度尽可能小，以利于机器人通过低矮空间；（5）结构简单、可靠性高、制造成本可控。'),
    bodyP('经过对丝杆升降机构、液压升降机构、同步带升降机构和剪叉式升降机构等常见方案的综合比较，本文选定剪叉式垂直升降机构。该机构利用两组交叉铰接的等长臂杆构成剪叉单元，通过改变臂杆间夹角实现平台的高度调节。其优势在于：结构紧凑，折叠高度低，能够获得较大的升程比；平台水平度保持性好，无须额外调平机构；承载能力通过增减剪叉层数和调整臂杆截面可灵活配置；采用电机经减速器驱动底部滑动端时，具备良好的可控性和定位精度。'),
    h3Text('3.1.2 机构结构组成'),
    bodyP('本文设计的单层剪叉式垂直升降机构主要由以下构件组成：'),
    bodyP('（1）剪叉臂杆——两根等长臂杆（各600 mm，销孔中心距）在中点处通过中心铰轴交叉连接，构成一个剪叉单元。臂杆采用36 mm × 4.8 mm的Q235实心扁钢，宽面竖直布置以提供抗弯刚度。', { noIndent: true }),
    bodyP('（2）底座固定铰座——位于机构底部左侧，将臂杆A的下端与车体框架刚性铰接，约束水平和竖直方向的平动自由度，仅允许绕铰轴的转动。', { noIndent: true }),
    bodyP('（3）底座滑动导轨——位于机构底部右侧，为臂杆B的下端提供水平滑动导向。滑动端通过滑块在导轨槽内直线运动，以适应升降过程中臂杆投影长度的变化。', { noIndent: true }),
    bodyP('（4）顶部固定铰座——臂杆B的上端与承载平台底部铰接，约束平动自由度。', { noIndent: true }),
    bodyP('（5）顶部滚轮机构——臂杆A的上端通过两个滚轮在承载平台底部的导向槽内滚动，以滚动摩擦代替滑动摩擦，降低运动阻力并提高升降平稳性。', { noIndent: true }),
    bodyP('（6）中心铰轴——连接两根臂杆的中点，传递两臂之间的相互作用力，直径18 mm，材料为45号钢。', { noIndent: true }),
    bodyP('（7）承载平台——660 mm × 312 mm × 3 mm的Q235钢板，作为货物直接承载面。', { noIndent: true }),
    bodyP('各铰接点均采用直径为18 mm的45号钢圆柱销作为连接件，配合耳板构成转动副。所有焊接节点均经过去应力处理，以减少焊接残余变形对装配精度的影响。'),
    h3Text('3.1.3 材料选择'),
    bodyP('剪叉臂杆选用Q235普通碳素结构钢，其主要性能参数如表3-1所示。Q235钢屈服强度为235 MPa，抗拉强度为375 MPa，延伸率不低于26%，弹性模量约为2.06 × 10⁵ MPa，具有良好的焊接性能和常温冲击韧性。该材料在机械制造行业应用广泛，采购成本较低，加工工艺成熟，能够满足本设计的承载需求。销轴选用45号优质碳素结构钢，屈服强度为355 MPa，表面经调质处理以提高耐磨性。承载平台和底座板选用Q235钢板，与臂杆材料保持一致，便于焊接和整体加工。'),
    ...tbl(3, 1, 'Q235钢的主要性能参数',
      ['性能指标', '数值范围/说明'],
      [['屈服强度 σₛ', '≥ 235 MPa'],
       ['抗拉强度 σ_b', '375 ~ 500 MPa'],
       ['延伸率 δ', '≥ 26%'],
       ['弹性模量 E', '≈ 2.06 × 10⁵ MPa'],
       ['密度 ρ', '7.85 g/cm³'],
       ['泊松比 ν', '0.3'],
       ['焊接性能', '良好'],
       ['冲击韧性', '常温下具有良好韧性']]),
    ...fig(3, 1, '剪叉式升降机构三维模型'),
    h2Text('3.2 升降机构工作原理与运动学分析'),
    bodyP('剪叉式垂直升降机构的工作原理基于平面连杆机构的运动特性。两组等长臂杆在中心铰点处交叉连接，当底部滑动端在驱动力作用下水平移动时，两臂之间的夹角发生变化，进而带动顶部平台沿竖直方向上下运动。'),
    h3Text('3.2.1 运动学建模'),
    bodyP('设单根臂杆长度为L（销孔中心距），两臂间夹角为α，则臂杆与水平面的夹角（水平半角）为β = α/2。以底部固定铰点为坐标原点，水平方向为X轴，竖直方向为Z轴，可建立以下运动学关系。'),
    ...fig(3, 2, '剪叉式升降机构运动简图（最低位）'),
    ...fig(3, 3, '剪叉式升降机构运动简图（最高位）'),
    bodyP('台面高度H与水平半角β之间的关系为：'),
    ...eq(3, 1, 'H = L·sin(β) + h₀ = L·sin(α/2) + h₀',
      'L为臂杆长度（mm），β为臂杆与水平面的夹角（水平半角），h₀ ≈ 49 mm为臂杆两端配件对台面高度的固定贡献值'),
    bodyP('底部滑动端的水平位移xₛ与β之间的关系为：'),
    ...eq(3, 2, 'xₛ = L·cos(β)',
      'xₛ为底部滑动端水平位移（mm）'),
    bodyP('由式(3-1)和式(3-2)消去β，可得台面高度与滑动端位移之间的非线性关系：'),
    ...eq(3, 3, 'H = √(L² − xₛ²) + h₀',
      '各符号含义同式(3-1)、式(3-2)'),
    h3Text('3.2.2 工作参数'),
    bodyP('本设计中，臂杆长度L = 600 mm（不含两端配件）。在最低工作位置，两臂夹角αₘᵢₙ = 19.10°，对应水平半角βₘᵢₙ = 9.55°；在最高工作位置，两臂夹角αₘₐₓ = 133.49°，对应水平半角βₘₐₓ = 66.75°。由运动学公式计算得：'),
    bodyP('Hₘᵢₙ = 600 × sin(9.55°) + 49 ≈ 149 mm'),
    bodyP('Hₘₐₓ = 600 × sin(66.75°) + 49 ≈ 600 mm'),
    bodyP('理论最大升程约为452 mm，覆盖常用仓库货架的底层至中层取放需求。'),
    h2Text('3.3 升降机构受力分析与载重计算'),
    h3Text('3.3.1 额定载重设定'),
    bodyP('综合考虑智能仓储移动机器人的应用场景——中小型零件、料箱和半成品的垂直搬运——以及整车自重、底盘稳定性和驱动能力等因素，将承载平台的额定载重设定为Q₀ = 50 kg，取重力加速度g = 9.81 m/s²。对应的额定载荷力F = Q₀·g = 50 × 9.81 ≈ 490.5 N。在强度校核中，将以此额定载荷为基准，并引入安全系数以确保结构在冲击和偏载等异常工况下仍具有足够的承载能力。'),
    h3Text('3.3.2 剪叉臂受力分析'),
    bodyP('取最危险工况——平台位于最低位置（βₘᵢₙ = 9.55°）——进行受力分析。此时臂杆最接近水平状态，轴向力最大。平台总载荷F通过顶部四个铰接点传递至两根臂杆。假定载荷均匀分配，每个顶部铰接点承受F/4的竖直力。在顶部固定铰接点处，臂杆轴向力F_arm的竖直分量与铰点载荷平衡：'),
    ...eq(3, 4, 'F_arm · sin(β) = F / 4',
      'F_arm为单根臂杆轴向力（N），β为水平半角，F为平台总载荷（N）'),
    bodyP('由此得单根臂杆的轴向力表达式为：'),
    ...eq(3, 5, 'F_arm = F / (4 · sin(β))',
      '各符号含义同式(3-4)'),
    bodyP('代入数值βₘᵢₙ = 9.55°、F = 490.5 N：'),
    ...eq(3, 6, 'F_arm = 490.5 / (4 × sin 9.55°) ≈ 739.1 N',
      ''),
    bodyP('该轴向力以压缩形式作用于臂杆，同时臂杆还承受由自重引起的弯曲载荷。臂杆自重线载荷w为：'),
    ...eq(3, 7, 'w = ρ · A · g ≈ 0.0133 N/mm',
      'ρ为材料密度，A为臂杆截面面积，g为重力加速度'),
    bodyP('将臂杆简化为两端铰支的简支梁，自重产生的跨中最大弯矩为：'),
    ...eq(3, 8, 'M_self = w · L² · cos(β) / 8 ≈ 0.59 N·m',
      '各符号含义同前'),
    bodyP('此外，考虑制造和装配过程中不可避免的偏心误差，保守取偏心距e = 2 mm，其引起的附加弯矩为：'),
    ...eq(3, 9, 'M_ecc = 0.5 · F_arm · e ≈ 0.74 N·m',
      'e为偏心距（mm）'),
    bodyP('综合弯矩最大值M_max ≈ 1.33 N·m。'),
    h3Text('3.3.3 各工作角度下的受力变化'),
    bodyP('平台在不同高度位置时，臂杆水平半角β发生变化，导致臂杆轴向力相应改变。表3-2列出了额定载荷下各典型工作角度对应的受力值。'),
    ...tbl(3, 2, '不同工作角度下的受力对比（Q₀ = 50 kg）',
      ['两臂夹角α（°）', '半角β（°）', '台面高度H（mm）', '臂轴向力F_arm（N）'],
      [['19.10', '9.55', '149', '739.1'],
       ['20.00', '10.00', '153.2', '706.2'],
       ['30.00', '15.00', '204.3', '473.8'],
       ['40.00', '20.00', '254.2', '358.5'],
       ['50.00', '25.00', '302.6', '290.2'],
       ['133.49', '66.75', '600', '133.5']]),
    bodyP('由表可见，臂杆轴向力随平台升高（β增大）而显著减小，最低位时臂杆轴向力达到最大值739.1 N，约为最高位时的5.5倍。因此在机构设计时应以最低位工况作为最危险工况进行强度校核。'),
    h2Text('3.4 关键部件强度校核'),
    h3Text('3.4.1 剪叉臂杆截面特性'),
    bodyP('臂杆采用36 mm × 4.8 mm的Q235实心扁钢，设截面宽度为B = 4.8 mm、截面高度为H = 36 mm，宽面沿竖直方向布置以增强抗弯能力。其截面特性计算如下：'),
    ...eq(3, 10, 'A = B · H = 4.8 × 36 = 172.8 mm²', 'A为截面面积'),
    ...eq(3, 11, 'I_强 = BH³/12 ≈ 18662 mm⁴', 'I_强为强轴惯性矩（竖直面内弯曲）'),
    ...eq(3, 12, 'I_弱 = HB³/12 ≈ 332 mm⁴', 'I_弱为弱轴惯性矩（侧向弯曲）'),
    ...eq(3, 13, 'W = I_强 / (H/2) ≈ 1037 mm³', 'W为抗弯截面模量'),
    ...eq(3, 14, 'i_min = √(I_弱 / A) ≈ 1.39 mm', 'i_min为最小回转半径'),
    h3Text('3.4.2 臂杆压弯组合强度校核'),
    bodyP('在轴向压力与弯矩的共同作用下，臂杆处于压弯组合应力状态。轴向压应力为：'),
    ...eq(3, 15, 'σ_a = F_arm / A = 739.1 / 172.8 ≈ 4.28 MPa', 'σ_a为轴向压应力'),
    bodyP('弯曲正应力为：'),
    ...eq(3, 16, 'σ_b = M_max / W = 1.33 × 10³ / 1037 ≈ 1.28 MPa', 'σ_b为弯曲正应力'),
    bodyP('截面上两应力叠加，压弯组合最大应力出现在截面受压侧边缘：'),
    ...eq(3, 17, 'σ_max = σ_a + σ_b = 4.28 + 1.28 = 5.56 MPa', ''),
    bodyP('取安全系数n_s = 1.5，Q235钢屈服强度σ_s = 235 MPa，则许用应力为：'),
    ...eq(3, 18, '[σ] = σ_s / n_s = 235 / 1.5 ≈ 156.7 MPa', ''),
    bodyP('σ_max = 5.56 MPa ≪ [σ] = 156.7 MPa，臂杆强度满足设计要求，应力利用率仅为3.5%，具有充足的安全余量。'),
    h3Text('3.4.3 臂杆屈曲稳定性校核'),
    bodyP('臂杆为细长受压构件，需校核其整体稳定性。由于臂杆截面为扁钢，弱轴方向的惯性矩远小于强轴方向，因此侧向屈曲是稳定性的控制因素。将臂杆简化为两端铰支的压杆，长度系数μ = 1.0，有效长度L_eff = μL = 600 mm。弱轴方向的长细比为：'),
    ...eq(3, 19, 'λ = L_eff / i_min = 600 / 1.39 ≈ 431.7', 'λ为长细比'),
    bodyP('Q235钢的比例极限长细比约为λ_p ≈ 104。由于λ = 431.7 > λ_p，该杆属于大柔度压杆，其临界载荷采用欧拉公式计算：'),
    ...eq(3, 20, 'F_cr = π² · E · I_弱 / L_eff² ≈ 1874 N', 'F_cr为欧拉临界载荷，E = 2.06 × 10⁵ MPa为弹性模量'),
    bodyP('取屈曲稳定安全系数n_buckle = 3.0，则：'),
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

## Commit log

2026-04-18 Add QLUThesis LaTeX template and references
    - Created a new LaTeX template for QLU undergraduate theses, including structured sections for acknowledgments, abstract, body, and references.
    - Added a reference.bib file with various citations in both English and Chinese.
    - Introduced a README.md file detailing the usage of the template, installation instructions, and compilation methods.
    - Included a sample document structure for better organization and ease of use.
2026-04-19 chore: track font-packages zip with git lfs
2026-04-29 调整正文用语使其更符合本科生论文水平
2026-04-29 初始提交：毕业论文项目结构
    - 论文 LaTeX 模板与正文内容
    - 差速双轮机器人 PID 控制 MATLAB/Simulink 仿真
    - 添加 .gitignore 排除构建产物和缓存文件
2026-05-09 sync: merge thesis updates, remove large font zips from tracking
    [reference_path.csv]
2026-05-12 Reorganize matlab files and update .gitignore
    [reference_path.csv]
2026-05-19 20号前的最后一版
2026-05-19 更新附录、仿真代码与图片资源
    - 附录新增程序5：剪叉式升降机构强度校核与载重分析程序
    - 更新MATLAB仿真文件（chasu.m、diff_drive_pid_sim.m、line_following_pid.m）
    - 更新PID仿真结果图片（阶跃响应、定点镇定、直线跟踪、圆形跟踪）
    - 新增循迹仿真结果图片
    - 删除过期附件 附录内容.zip
2026-05-19 重构附录、重写摘要、优化代码注释与文件命名
    - 重写中英文摘要：按"需求→成果→结论"逻辑重组，突出仿真数据，避免与前言/结论雷同（~420字）
    - 附录规范化：按"附录A（程序代码）+附录B（装配图）"分区，统一使用"附A1""图B1"编号
    - 代码文件重命名：chasu→traj_sim, hybrid_astar_pathplanning→hybrid_astar, line_following_pid→tracking_pid, diff_drive_pid_sim→pid_control, scissor_lift_strength_analysis→lift_strength
    - 代码注释去AI化：保留逐行注释但精简为自然笔记风格
    - 修复目录首页页眉缺失问题
2026-05-20 整理仓库结构：更新README、添加答辩PPT、清理冗余文件
2026-05-26 更新 .gitignore 排除 conda 环境，添加毕设相关文档，清理旧 word 脚本
2026-05-26 合并 bysj 到 base，清理 .gitignore
2026-05-26 修复 .gitignore 补回 .claude/
2026-05-26 备份: 准备补充有限元分析内容
2026-05-27 更新论文body.tex内容，添加有限元分析结果图
2026-05-27 添加答辩PPT美化版本
2026-05-27 统一PID参数与仿真图一致，修正附录强度校核代码
    - body.tex: 轮速环Kp 2→17, Ki 12→103, 电压限幅±12V→±24V, Km 0.33→0.327
    - lift_strength.m: 修正销轴跨度27mm、耳板厚度6mm、截面模量公式，修复变量名冲突
2026-05-27 修正附录scissor_lift_fea.m销轴参数与偏心弯矩
    - 销轴跨度: H_arm+6(42mm) → 27mm (耳板内间距)
    - 耳板承压厚度: B_arm(4.8mm) → t_ear(6mm)
    - 补充偏心弯矩 M_ecc=0.5*F_arm*ecc，与论文一致
2026-05-27 修正销轴材料为45#钢(σ_y=355MPa)，与论文一致
    - lift_strength.m: 销轴剪切用45#钢tau_allow=142MPa替代Q235的94MPa
    - scissor_lift_fea.m: 同上，补充F_pin双剪承载力计算
    - 删除lift_strength.m中未使用的sigma_brg_allow错误定义
2026-05-27 修复scissor_lift_fea.m categorical+string类型错误
    string()改为num2str()，与lift_strength.m保持一致
2026-05-27 修正结论§7.2章节引用，使其与正文第5、6章对应
2026-05-28 全编译更新：更新body.tex、PID代码、图片资源及答辩PPT
2026-05-28 更新答辩PPT、级联PID模型及论文插图代码
2026-05-28 更新总装图、替换答辩PPT
2026-05-28 压缩总装装配图（31680x24480→3500x2704），减小PDF体积
2026-05-29 删除附录B装配图（6张图纸）
2026-05-30 回应盲审意见：补充减速器选型分析与实物测试计划
    1. 减速器章节：补充40倍减速比对低速控制精度和启动转矩的影响分析
    2. 结论章节：补充三阶段实物验证工作计划（空载调试→负载测试→完整任务测试）
2026-06-03 更新论文正文、仿真代码及答辩材料
    [app.xml]
2026-06-04 sync: 附录程序与D:\code\matlab源码同步，修正函数名与路径
2026-06-04 docs: 附录程序逐行补全中文注释，绘图/算法/输出全覆盖
2026-06-04 整理工作区：完成答辩PPT最终版、原理图、工作区清理
    - 答辩PPT最终版 ppt.pptx（10页，含演讲稿备注）
    - 新增 kinematics_principle.svg 运动学原理图
    - 更新 dual_loop_pid_vertical.svg 修复箭头连接
    - 整理旧文件至 答辩PPT/旧版本/
    - 清理根目录临时SVG和脚本
    [app.xml]
2026-06-04 更新README：匹配论文最终信息（题目、作者、仿真结果）
2026-06-04 README添加分章节字数统计
2026-06-06 双环PID对比实验+全图拆分+论文更新
    - run_all.m: 新增单环PID对照组, 双环vs单环对比, 加入负载扰动
    - b_pid_control.m: subplot拆分为6张独立图
    - g_scissor_lift_fea.m: subplot拆分为6张独立图
    - f_lift_strength.m: subplot拆分为6张独立图
    - a_traj_sim.m: tiledlayout拆分为3张独立图
    - body.tex: 新增对比表+4张轨迹对比图+参数整定说明
    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
2026-06-06 修复论文组图引用: 对比图替换旧合并图, 所有MATLAB配图拆分为独立figure
    - body.tex: 6.4节4张旧合并图替换为独立对比图
    - run_all.m: 移除b_pid_control自动调用
    - 所有figures同步更新
2026-06-06 修复FEA组图: fea_results_50kg.png拆为4张独立图
2026-06-06 修复排版: 所有figure从[H]改为[htbp], 避免单独图页
2026-06-06 精简FEA图: 4张减为2张, 图间加文字过渡, 避免单独图页
2026-06-06 全文排版修复: 连续图间加文字过渡, 修复缺少begin figure错误
2026-06-06 所有table从[H]改为[htbp], 避免单独表格页
2026-06-06 PID对比章节加公式: 双环控制律、单环控制律、RMSE定义
2026-06-06 全文公式补充: Hybrid A*代价函数+抗饱和公式+稳定性分析+传感器距离公式
2026-06-06 README更新: 双环PID对比数据+FEA结果+答辩评审意见
2026-06-06 README: 评语改为原封不动全文
2026-06-06 添加论文PDF到git + .gitignore允许thesis main.pdf
2026-06-06 减少论文图数: 第四章电路图合并(13→7张), 第三章机构图加文字
2026-06-06 PID对比部分扩充文字: 每个场景详细分析, 避免连续图页
2026-06-06 figure改回[H]强制就地放置, 确保图文对应
2026-06-06 减少浮动体间距: textfloatsep/floatsep/intextsep, 减少[H]留白
2026-06-06 加raggedbottom: 允许页面高度不等, 消除底部大量留白
2026-06-06 直线跟踪→S形轨迹: 场景3改为v=0.3+w=0.8sin(t), 加参考轨迹反馈
2026-06-06 线速度对比图加局部放大: 每个场景右上角放大关键段
2026-06-06 论文加线速度对比图: 阶跃和S形的局部放大图插入对比分析段
2026-06-06 轨迹对比图加局部放大: S形和圆形左上角放大重合段, 去掉不需要的速度放大图
2026-06-06 圆形轨迹对比去掉放大, 仅S形保留局部放大
2026-06-06 循迹轨迹图加局部放大: tracking_pid右下角放大路径中段
2026-06-06 加双环PID结构框图: 重绘无坐标轴版, 插入6.2节开头
2026-06-06 PID结构框图优化: 箭头指向方块边缘, 不再穿过
2026-06-06 PID框图再次优化: e_ω可见、箭头不穿虚线框、ω_L标签上移
2026-06-06 PID框图: 箭头从虚线框下方指向电机, 不再穿过方块
2026-06-06 PID框图: 箭头绕过虚线框指向电机, 不再穿过任何方块
2026-06-06 删除PID结构框图: 画不好看, 去掉
2026-06-06 加3张未用图: 台面挠度云图+臂变形图+应力分量图
2026-06-06 精简论文内容: 消除重复数据、优化图文顺序、修复格式细节
    - FEA验证: 整合散布的应力/挠度数据为集中对比段,图连续排列
    - 第五章: 删除轮速分析重复段,曲率描述补回圆弧对比,v_cmd/w_cmd图
    合并引导句,删除与第二章重复的A*对比,精简表格前后冗余文字
    - 第六章: 删除对比总结段中重复的9.6倍/33%数据
    - 小结/结论: 删除与正文重复的具体数字,改为定性总结
    - 第四章: 删除传感器接口小节中第三次重复的功能描述
    - 致谢: 改为正式学术口吻,删除散文式表达
    - 表格字号: 为tab:traj_summary和tab:line_following_result添加\wuhao
    - 删除根目录散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
2026-06-06 README: 修正章节数(6→7), 补充aop.tex和MATLAB文件列表
2026-06-06 答辩文档: 补充双环vs单环对比问答和自检条目
2026-06-06 README: 重写为系统架构+核心指标+工作量总览的展示风格
2026-06-06 README: 修正字数统计为实际值(CN~26260/EN~4964/合计~31200)
2026-06-06 README: 修正字数统计,分正文字数/含公式两列,数据来自实际统计
2026-06-06 README: 字数改为LaTeX统计的26820字
2026-06-06 README: 字数统计改为texcount逐章统计(CN总计25567)
2026-06-07 修正摘要与正文对应: 直线跟踪→S形轨迹跟踪, 添加.gitignore, 重新编译PDF
    - 中文摘要: 直线跟踪 → S形轨迹跟踪 (与第六章实际仿真工况一致)
    - 英文摘要: straight-line tracking → S-curve trajectory tracking
    - 添加.gitignore排除LaTeX编译中间文件
    - 重新编译main.pdf (100页)
    - 项目完整文件: 源码/图片/字体/MATLAB脚本/参考文献均已追踪, 可直接复现
2026-06-07 README: 补充完整答辩评审评语(指导教师/评阅专家/答辩组)
2026-06-07 README: 添加开发日志(54天80+次提交的论文写作历程)
2026-06-07 README: 更新字数统计(texcount逐章27785字+61浮动体)并同步main
2026-06-09 重组项目结构: 将 code/ 子目录内容提升到仓库根目录
    - MATLAB仿真、LaTeX论文、答辩材料等从 code/ 移到根目录
    - 新增 翻译/、开题/、中期检查/、嘉立创单片机原理图/ 等目录
    - 更新 .gitignore 排除 node_modules、.conda、字体zip等大文件
    - 保留旧仓库 80+ 次提交历史
    [111111111.SLDASM, 3222.SLDASM, AGV罩壳.SLDPRT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]
2026-06-09 README: 移动到根目录并更新项目结构路径
2026-06-09 清理: 删除旧版PPT、SW备份、IDE配置，更新.gitignore
2026-06-09 优化: Hybrid A*仿真+循迹PID参数调优，论文同步更新
    - Hybrid A*: 障碍物膨胀(r=0.38m)、3D航向栅格去重、解析扩展、加权均值平滑
    - 循迹PID: 参数扫描优化(Kp=3, Kd=0.8~2, v=0.25, ma=6)，RMS误差0.8→0.58cm
    - 论文: 更新第五章算法描述、仿真结果、摘要、结论，重新编译PDF
2026-06-09 修复: 附录代码bspline_smooth→weighted_avg_smooth，重新编译PDF
2026-06-09 封面: 添加第二导师王月光
2026-06-09 封面: 导师行合并刘鹏博与王月光
2026-06-09 第四章: 四级标题添加序号(4.1.1.1~4.1.1.4)，修复secnumdepth被覆盖为2的问题
2026-06-30 整理: 同步论文源文件与成果文件
    [tracking_compare_results.csv, 万向轮.DWG, 万向轮.dxf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]
2026-06-30 整理: 归档成果压缩包
2026-06-30 文档: 更新README字数统计
